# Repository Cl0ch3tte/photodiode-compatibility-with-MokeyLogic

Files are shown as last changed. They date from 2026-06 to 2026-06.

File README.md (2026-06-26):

# photodiode-compatibility-with-MokeyLogic

Open-hardware photodiode circuit that generates sub-millisecond event markers
synchronized with on-screen visual stimuli on a 144Hz display, designed to
complement eye-tracking data collected with MonkeyLogic.

# Overview
The detector converts a light signal into an electrical signal using a
photodiode and a transimpedance amplifier (TIA), then compares it to an
adjustable threshold to produce a clean logic signal. An Arduino timestamps
this signal in microseconds and streams it over USB serial; a Python script
logs it to CSV, which can then be merged with keyboard-generated event
markers for full experimental synchronization.

# Hardware

- **Photodiode:** SFH206K
- **Amplifier:** LM358 (single dual op-amp: one stage as TIA, one as
  threshold comparator with hysteresis)
- **Supply:** single 5V rail
- **Output:** BNC (analog) + digital logic line to the Arduino

Full schematic, component justification, and bill of materials are in
[`docs/Dossier_de_conception.pdf`](docs/Dossier_de_conception.pdf).

## Firmware

The Arduino reads the comparator's digital output, timestamps it with
`micros()`, and writes `timestamp,state` lines over USB serial at 115200
baud.

## Software

`acquisition_pcclock.py` logs the Arduino stream to a timestamped CSV.
`merge_file_auto.py` aligns and merges the Arduino CSV with a keyboard
marker CSV (useful when acquisition runs across two separate PCs), using a
shared SYNC marker as the time reference.

## Getting started

1. Build the circuit following the schematic
2. Flash 'test_arduino.ino' to the Arduino.
3. Run `acquisition_pcclock.py` to start logging.
4. Use `merge_file_auto.py` if combining with keyboard event markers.

Chloé Lapaquellerie — BUT GEII, IUT Lyon 1
Internship at INSERM SBRI Lyon, Dehay team (Cerebral Cortex and Connectome)

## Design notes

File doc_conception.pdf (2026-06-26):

# Conception d’un détecteur photodiode pour

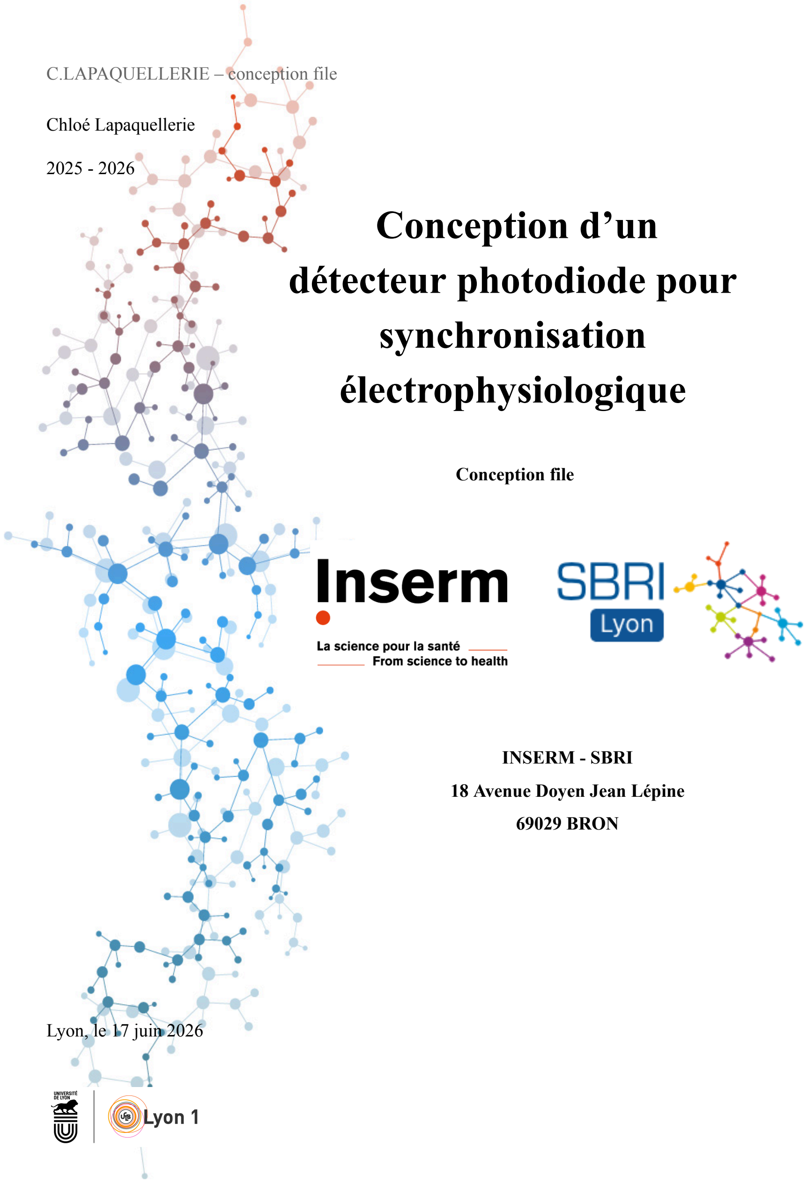
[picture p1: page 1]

C.LAPAQUELLERIE – conception file

Chloé Lapaquellerie

2025 - 2026

# synchronisation électrophysiologique

Conception file

INSERM - SBRI

### 18 Avenue Doyen Jean Lépine

69029 BRON

Lyon, le 17 juin 2026

C.LAPAQUELLERIE – Conception File | 2

## Abstract

Ce rapport présente les travaux réalisés lors d'un stage de dix semaines au sein de l'équipe Dehay-Kennedy de l'Institut Cellule Souche et Cerveau, INSERM U 1208 Lyon, dans le cadre d'une deuxième année de BUT Génie Électrique et Informatique Industrielle. La mission confiée consiste à concevoir et réaliser un circuit électronique de détection optique destiné à synchroniser des stimuli visuels avec des enregistrements électrophysiologiques, ainsi qu’une étude comportementale avec une précision temporelle inférieure à la milliseconde. Le circuit repose sur une photodiode SFH206K associée à un amplificateur opérationnel (AOP), le LM358, le circuit est alimenté en single supply 5V. Une chaîne d'acquisition complète a été développée, intégrant une carte Arduino UNO pour la récupération des données et un script Python pour l'enregistrement des données au format CSV. Le prototype a été validé en conditions réelles sur un écran LCD 144 Hz, le schéma KiCAD a été réalisé, ainsi qu’un boîtier en modélisation 3D à l’aide du logiciel de CAO Fusion 360. En vue d’avoir un projet complet et réutilisable par d’autres laboratoires, un dossier complet est en finalisation sur la plateforme GitHub.

## Table des matières

Table des Illustrations et tableaux | 9
Table des Annexes | 10
Introduction Générale | 13
I. INSERM, un institut ancré | 15
I.1 L’INSERM en quelques mots | 15
I.2 Objectifs et but | 16
I.3 Planning du stage | 16
II. INSERM Lyon | 18
II.1 INSERM Lyon - site de Bron | 18
II.2 L’équipe Dehay-Kennedy: Cerebral Cortex and Connectome | 19
III. Présentation de la mission | 21
III.1 Objectifs | 21
III.2 Analyse préliminaire | 21
III.3 Contraintes et enjeux | 22
IV. Mise en oeuvre de la mission | 23
IV.1 Analyse complète | 23
Etage 1 : amplificateur transimpédance (TIA) | 24
Etage 2 : comparateur | 27
IV.2 Test avec le premier prototype | 28
IV.3 Débogage - problèmes rencontrés et solutions | 30
Problème 1 : photodiode montée à l’envers | 31
Problème 2 : zone morte du LM358 en single supply | 31
IV.4 Réalisation du PCB avec KICAD | 32
IV.5 Réalisation du boîtier en CAO | 34
IV.6 Acquisition des données script Python et Arduino | 36
Architecture | 36
IV.7 Premiers résultats (au 16 juin 2026, veille de rendu) | 41
V. Conclusion Générale | 43
VI. Bilan technique | 44
VI.1 Résultats et évaluation | 44
VI.2 Discussion et analyse des solution retenues | 45
VII. Bilan de Compétences | 47
VII.I Concevoir la partie GEII d’un système | 47
VII.II Implanter la partie GEII d’un système | 50
VII.III Vérifier la partie GEII d’un système | 54

VII.IV Maintenir la partie GEII d’un système | 58
VIII. Bilan personnel | 59
VIII.1 Discussion | 59
VIII.2 Avenir | 59
Appendix | 61
Références | 66

## Table des Illustrations et tableaux

Figure 2 – Organigramme du SBRI (2024) | 18
Figure 3 – Schéma électronique complet KiCAD | 23
Figure 4 – Architecture interne générale du LM358AP | 24
Figure 5 – Etage 1: le TIA | 25
Figure 6 – Etage 2: le comparateur | 27
Figure 7 – Montage sur breadboard | 29
Figure 8 – Première version du circuit - non fonctionnel | 30
Figure 9 – Plan du PCB sur KiCAD | 32
Figure 10 – Visualisation 3D de la carte électronique face-avant | 33
Figure 11 – Visualisation 3D de la carte électronique face-arrière | 33
Figure 12 – Boîtier en vue gauche-haut | 34
Figure 13 – boîtier vue bas-droite | 35
Figure 14 – Flowchart du programme Arduino | 37
Figure 15 – Flowchart programme Python | 39
Figure 16 – Exemple d’un enregistrement de fichier | 40
Figure 17 – Exemple d’utilisation du fichier CSV sur excel | 41
Figure 18 – Brouillon n°1 des calculs | 48
Figure 19 – Brouillon n°2 des calculs | 49
Figure 20 – Premier prototype du circuit | 50
Figure 21 – Recherches sur le boîtier | 52
Figure 22 – Recherches sur le boîtier n°2 | 53
Figure 23 – Premiers tests avec l’oscilloscope et prise de notes PC | 54
Figure 24 – Prise de notes pendant une phase de tests | 56
Figure 25 – Prise de notes pendant la phase de tests final | 57
Tableau 1 – Contraintes et enjeux | 22
Tableau 2 – Compétences GEII | 47

## Table des Annexes

Annexe I – Organigramme équipe Dehay | 61
Annexe II – Exemple d’une image de stimuli avec le carré de pixel pour la photodiode en haut
sur la droite | 61
Annexe III – Photodiode soudée sur l’autre face | 62
Annexe IV – Script Arduino | 63
Annexe V - Script Python Partie 1 | 64
Annexe VI – Script Python Partie 2 | 65

## Introduction Générale

Dans le cadre de ma deuxième année de BUT Génie Electrique et Informatique Industrielle (GEII), parcours Electronique et Systèmes Embarqués (ESE) à l’Université Claude Bernard Lyon 1, il est requis de réaliser un stage d’un minimum de 8 semaines au sein d’une entreprise se rapportant aux compétences acquises pendant le diplôme. J’ai ainsi effectué un stage de dix semaines de avril à juin au sein du laboratoire Stem Cell and Brain Research Institute (SBRI) unité Institut National de la Santé et de la Recherche Médicale (INSERM), en co-tutelle avec l’Université Claude Bernard Lyon 1.

Le projet est une extension à l’utilisation de MonkeyLogic. Les solutions actuelles répondent pour la plupart à des besoins spécifiques présentant donc des limitations. La nécessité d’avoir un système modulable et peu onéreux à pour objectif de proposer une solution adaptée et spécifique Le projet consiste à concevoir un système de mesure optique basé sur une photodiode. Le signal lumineux est converti en courant, puis transformé en tension via un amplificateur transimpédance (TIA) réalisé avec un LM358. Cette tension ainsi acquise, est transmise par un connecteur BNC, permettant le traitement du signal analogique selon le besoin.

Une seconde partie du circuit permet la détection d’un seuil lumineux grâce à un comparateur intégré dans le même amplificateur opérationnel. Les données sont ensuite transmises à une carte Arduino afin d’être enregistrées sous forme de fichier CSV.

Ce système permet donc à la fois une mesure analogique continue et une détection logique binaire.

## III. Présentation de la mission

III.1 Objectifs

L’objectif est de concevoir, mettre en place et utiliser un système électronique permettant de détecter l’apparition d’un stimulus lumineux sur un écran 144Hz. Depuis un cahier des charges, la mission permettait avec flexibilité, de concevoir le dispositif selon les besoins, insistant sur une précision temporelle à la milliseconde minimum dû à la fréquence d'échantillonnage du système de mesure des mouvements oculaires qui est de 1000 Hz, soit une mesure toutes les milliseconde. Ce système permet donc de générer deux signaux afin de satisfaire les besoins de l’équipe concernée :

- Un signal analogique proportionnel à l’intensité lumineuse, destiné à une carte d’acquisition NI BNC2090A via LabView notamment. Des paramétrages doivent être ajoutés sur cette sortie dans l’application, le montage étant un montage inverseur.
- Un signal numérique (HIGH/LOW) pour la détection d’événements et l'enregistrement des timestamps via Arduino. Utilisable directement grâce à un fichier python convertissant les données brutes en un fichier CSV.

III.2 Analyse préliminaire

Une première analyse a permis d’identifier les principales contraintes techniques du projet. D’abord, l’écran 144Hz, affichant 144 images par seconde soit une image toutes les 6.94ms. La détection doit donc être sur cette échelle de temps.

Le dispositif doit avoir une capacité de captation inférieure à 1ms, le stimuli étant envoyé toute les 1 ms, toutefois, le taux de rafraîchissement de l’écran nous permettrait une plus grande flexibilité.

Des composants initiaux étaient fournis, une photodiode, un potentiomètre, un AOP LM358, ces composants devaient apparaître dans le projet, autrement l’ajout d’autres composants était laissé libre. La solution retenue repose donc sur une architecture en deux étages : un amplificateur transimpédance (TIA) pour convertir le courant de la photodiode en tension, suivi d’un comparateur à Trigger Schmitt pour générer un signal logique propre.

III.3 Contraintes et enjeux

Plusieurs contraintes techniques ont orienté la conception du circuit:

Contraintes | Valeur | Justification
Résolution temporelle | <1ms | 144Hz = 6.94ms, apparition stimuli
durée de session | ~4h | Protocol expérimental
Alimentation | 5V/3A single supply | Suffisant, peu coûteux
Sorties | analogique + numérique | BNC2090A et Arduino
compatibilité | VSCode, Arduino, Python, C++, LabVIEW, Matlab? | outils disponibles au labo
stabilité thermique | dérive <1% sur 4h | SFH206K : +0.18%/K
Tableau 1 – Contraintes et enjeux | source: production personnelle

## I. Coût

X.1 Estimation du coût

Les produits présentés sont ceux qui ont été utilisés, tant que la référence est identique, le choix

du fabricant est quant à lui moins important.

Composant | Fabricant | quantité minimale
Coût | lien web (Mai
2026)

LM358 | Texas Instrument
(de préférence)
1 | 8.25€/5 unité | https://fr.rs-onlin e.com/web/p/am plificateurs-oper ationnels/197726
| | 5 (https://fr.rs-online.com/web/p/amplificateurs-operationnels/1977265) ou https://www.digi key.fr/fr/product s/detail/texas-ins truments/LM358 P/277042?gclsrc =aw.ds&gad_sou rce=1&gad_cam paignid=152153 454&gbraid=0A AAAADrbLlgq B2UV5AgsTN3 3TqG40FY_N& gclid=CjwKCAj wt7XQBhBkEiw AtStpp02cAwa8 KRMOzUmNhR BCu0NmLNIoIn 92SHsSUgylwN g7m5T8sxhbvho C04kQAvD_Bw E (https://www.digikey.fr/fr/products/detail/texas-instruments/LM358P/277042?gclsrc=aw.ds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)
SFH206K | AMS OSRAM | 1 | 6.05€ (5 unités) | https://fr.rs-online.com/web/p/photodiodes/654865 9 (https://fr.rs-online.com/web/p/photodiodes/6548659)
Résistance 1MΩ | TE Connectivity | 2 | 1.55€/10 unités | https://fr.rs-online.com/web/p/resi stances-traversan tes/2141535 (https://fr.rs-online.com/web/p/resistances-traversantes/2141535)
Résistance 10kΩ | Arcol | 4 | 3.50€/5 unité | https://fr.rs-online.com/web/p/resi stances-traversan (https://fr.rs-online.com/web/p/resistances-traversantes/4877141)

| | | | tes/4877141 (https://fr.rs-online.com/web/p/resistances-traversantes/4877141)
Capacité 100pF | TDK | 1 | 1.70€/10 unités | https://fr.rs-online.com/web/p/con densateurs-cera mique-monocou che/2621945 (https://fr.rs-online.com/web/p/condensateurs-ceramique-monocouche/2621945)
Coût total depuis les références (sans frais de port) = 65.79€ PT-10 | Amphenol Piher Sensing Systems | 1 | 0.48$/unité | https://www.digikey.fr/fr/products/detail/ampheno l-piher-sensing-s ystems/PT10MH 01-103A2020-I-PM-S/9555907 (https://www.digikey.fr/fr/products/detail/amphenol-piher-sensing-systems/PT10MH01-103A2020-I-PM-S/9555907)
Bloc de jonction CI série MKDSN 2.5/2-5.08 2 contacts Phoenix Contact | Phoenix contact | 2 | 1.07€/unité | https://fr.rs-online.com/web/p/bor niers-enfichables /8045095 (https://fr.rs-online.com/web/p/borniers-enfichables/8045095)
RS PRO BNC Connecteur BNC Femelle Montage sur circuit imprimé 50 Ω Soudure Droit | RS PRO | 1 | 2.79€/unité | https://fr.rs-online.com/web/p/con necteurs-coaxiau x/5260279 (https://fr.rs-online.com/web/p/connecteurs-coaxiaux/5260279)
Bloc d’alimentation 5V | RS PRO | 1 | 7.47€/unité | https://fr.rs-online.com/web/p/adaptateurs-ac-dc/1753297?searchId=04d6a79d-95de -4a1f-9e7f-f3b0f f57944d (https://fr.rs-online.com/web/p/adaptateurs-ac-dc/1753297?searchId=04d6a79d-95de-4a1f-9e7f-f3b0ff57944d)

## IV. Mise en oeuvre de la mission

IV.1 Analyse complète

L’analyse complète du besoin et des composants nous a amené sur un circuit organisé en deux étages, exploitant les deux amplificateurs du LM358. La photodiode étant fondamentalement une source de courant, il est nécessaire de transformer cette dernière en tension afin d’être une source exploitable. En effet, la photodiode capte la quantité de lumière reçue et génère un courant proportionnel à cette quantité de l’ordre de quelques microampères, ce courant est trop faible en tant que tel et dans le mauvais format, ne permettant pas son utilisation. Un système d’acquisition s’attend à une tension, pas un courant pour fonctionner. Ainsi, un premier étage est câblé en Amplificateur transimpédance (TIA) qui permet de convertir le courant de la photodiode en tension avec un gain Rf = 1MΩ. Le second étage est lui un comparateur à seuil fixe. Il compare la sortie du TIA à une tension seuil déterminée avec le potentiomètre et donne donc un signal logique de déclenchement. Le schéma électronique suivant présente la configuration finale du projet:

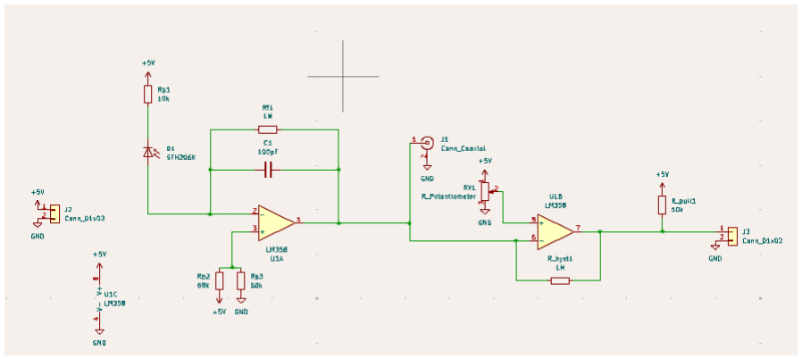
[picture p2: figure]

Figure 3 – Schéma électronique complet KiCAD | source – production personnelle

Le choix du LM358 tant bien qu’imposé nous a laissé une certaine flexibilité. Compatible avec une alimentation simple 5V (single supply), le circuit a été architecturé autour de cette contrainte. Nous pouvons constater dans la figure suivante représentant l’architecture générale du LM358, qu’il possède bien deux étages, les deux étant utilisés dans notre montage.

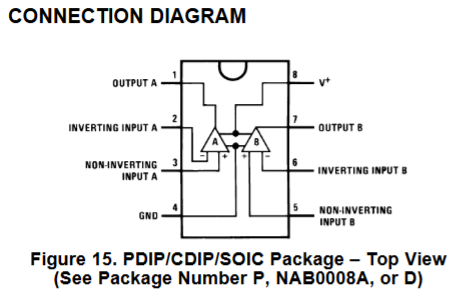
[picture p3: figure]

Figure 4 – Architecture interne générale du LM358AP | source – datasheet LM358 Texas
Instrument

Toutefois, la compréhension du single supply et de l'interaction avec l’AOP n’était pas tout à fait maîtrisée, nous amenant à une reconstruction partielle du circuit après une phase de test et un début de mise en place. Des étapes qui seront décrites ultérieurement dans ce rapport.

Etage 1 : amplificateur transimpédance (TIA)
Le rôle du TIA est de convertir le courant généré par la photodiode en une tension. Pour se faire, on s’appuie sur un principe de base d’un AOP idéal en boucle fermée: les deux entrées sont maintenues à la même tension par une boucle de contre-réaction. Ce comportement est dû au fonctionnement de l’AOP en régime linéaire qui cherche à minimiser la différence de potentiel entre ses entrées conformément à l’équation ε = V+ - V- ~ 0.

Le pont diviseur maintient la tension non inverseuse (pin 3) à une valeur Vref. Simultanément, la boucle de contre-réaction force la pin 2 à rester à une valeur proche de Vref. Cette entrée se comporte donc comme un nœud de référence virtuel, qui peut être appelé masse virtuelle puisque Vref joue le rôle de référence sur le montage ici.

On peut voir sur la figure suivante le TIA avec une première partie du LM358, la boucle de rétroaction, le pont diviseur en pin 3 ainsi que la photodiode.

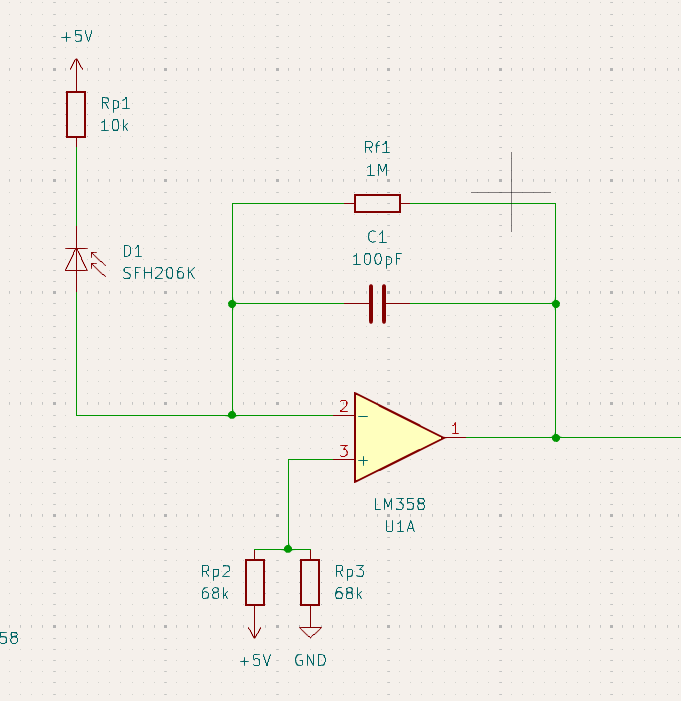
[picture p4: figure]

Figure 5 – Etage 1: le TIA | source – production personnelle

La photodiode SFH206K est polarisée en mode photoconducteur. Sa cathode est reliée au rail 5V via une résistance de 10kΩ, son anode est connectée à l’entrée inverseuse du premier AOP (pin2) du LM358. La résistance Rf = 1MΩ placée en parallèle avec le condensateur Cf = 100pF est connectée entre la sortie (pin1) et l’entrée inverseuse (pin2). L’entrée non-inverseuse (pin3) est connectée au nœud d’un pont diviseur composé de deux résistances 68kΩ en série entre le rail 5V et le GND, fournissant ainsi une tension première tension de référence Vref1 ~2.5V. Ce choix est imposé par une limitation physique du LM358 en alimentation single supply. En effet, sa plage d’entrée en mode commun ne s’étend pas jusqu’à 0V ni 5V, elle est légèrement au-dessus du 0V, et en dessous du 5V. Avec le pin3 directement à 0V, l’AOP entre dans une zone morte où il ne peut plus amplifier correctement et sature sa sortie vers le bas quelle que soit la différence d’entrée. En relevant le pin 3 à ~2.5V soit la moitié de la plage de la tension d’entrée, on a donc une plage virtuelle pour l’AOP de -2.5V à +2.5V, permettant l’utilisation réelle de l’AOP, sans dépasser le comportement normal et usuel du composant. Nous rentrerons dans de plus amples détails sur ce fonctionnement ultérieurement.

La fonction de transfert du TIA simplifiée est: Vout = Vref - Iph x Rf

En basse fréquence, Zf ~ Rf = 1MΩ. La fréquence de coupure du filtre RC est donc fc = 1/(2.π.Rf.Cf) ~1.6kHz largement suffisant pour détecter les transitions liées à l’apparition du stimulus sur l’écran 144Hz.

Du fait de la configuration inverseuse du TIA, la tension en sortie (pin 1) diminue lorsque la luminosité augmente par rapport à Vref. Ainsi, à l’obscurité pin1 est proche de 2.5V, tandis qu'en présence du stimulus blanc (de 60x60 pixels) à l'écran, pin 1 descend de manière significative en dessous de 2.5V. Ce comportement est corrigé au niveau du comparateur par le réglage du seuil avec le potentiomètre. Pour la sortie analogique, la correction se fera dans le logiciel associé à la carte d’acquisition.

Enfin, le condensateur Cf est essentiel à la stabilité du montage afin de limiter les oscillations parasites dûes au gain élevé de 1MΩ et les effets liés à la capacité de jonction de la photodiode.

Etage 2 : comparateur

Le second AOP du LM358 est câblé en comparateur. Son entrée inverseuse (pin 6) est reliée à la sortie du TIA (pin 1). Son entrée non-inversée (pin 5) reçoit la tension de seuil fournie par le potentiomètre câblé entre le +5V et le GND. Cette tension seuil est déterminée à la mesure en tension au pin 1. On récupère la valeur avec lumière et à l’obscurité, on place le curseur du potentiomètre sur la valeur milieu de la plage trouvée. On retrouve dans la figure ci-après la configuration du deuxième étage avec la deuxième partie du LM358, la résistance d'hystérésis et celle de pull-up ainsi que le potentiomètre.

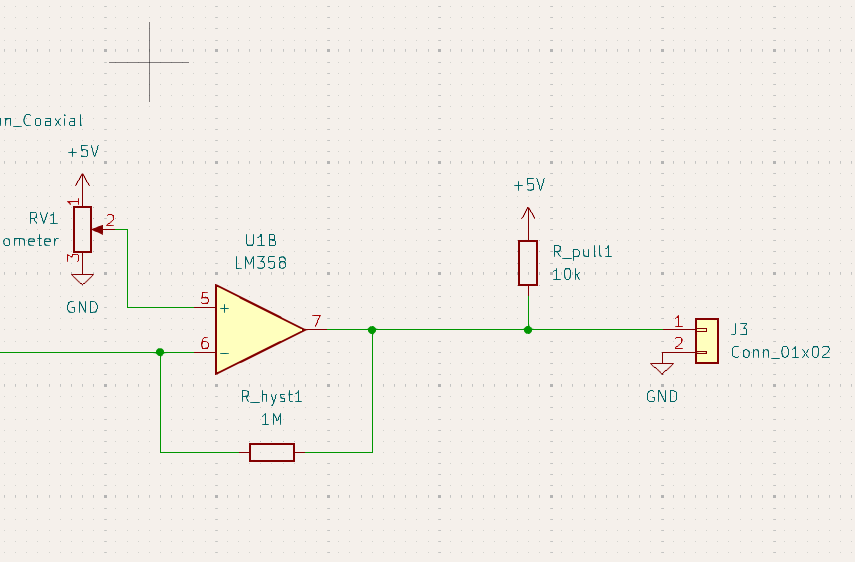
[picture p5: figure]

Figure 6 – Etage 2: le comparateur | source – production personnelle

Une résistance de pull-up est placée entre le +5V et la sortie (pin 7), celle-ci est indispensable. De fait, son intérêt vient directement de l’architecture interne du composant. Le LM358 présente une sortie à collecteur ouvert NPN, il fonctionne comme un interrupteur commandé, c’est-à-dire quand le comparateur décide que la sortie doit être LOW, le transistor entre en conduction et relie la pin de sortie au GND, il absorbe donc le courant. En revanche, quand le comparateur décide que la sortie doit être HIGH, le transistor se bloque, laissant la sortie flottante, sans la relier à l’alimentation. Sans résistance de pull-up, la sortie en état HIGH serait donc reliée à rien et la tension mesurée est autour de 0.66V, soit la mesure de la tension “résiduelle” du composant, donc ni un état logique HIGH, ni un LOW.

Enfin, une résistance d’hystérésis Rhyst = 1MΩ est connectée entre la sortie (pin 7) et l’entrée non-inverseuse (pin 5). Elle introduit une légère rétroaction positive qui élargit la zone de basculement du comparateur, évitant les oscillations parasites lorsque le signal d’entrée est proche du seuil. La logique du système est donc la suivante:
- Pas de stimulus à l’écran - Fond noir : pin 1 ~2.5V → pin 6 > pin 5 → pin 7 = LOW (~0V)
- Stimulus blanc à l’écran : pin 1 descend sous le seuil → pin 6 < pin 5 → pin 7 = HIGH (~4.6V)
Le seuil est réglé avec le potentiomètre pour se situer entre la valeur de pin 1 en fond noir et la valeur pin 1 avec la tâche blanche. Ce réglage est effectué une fois en conditions réelles d’utilisation et dépend de la luminosité de l’écran et des conditions d’éclairages ambiant.

IV.2 Test avec le premier prototype

Un prototype sur platine d’essai a été réalisé avant le PCB afin de valider le principe de fonctionnement. Ces tests étaient d’abord effectués en utilisant le flash d’un téléphone, rendant les mesures plus simples que sur un écran. Comme le montre la configuration dans la figure ci-contre:

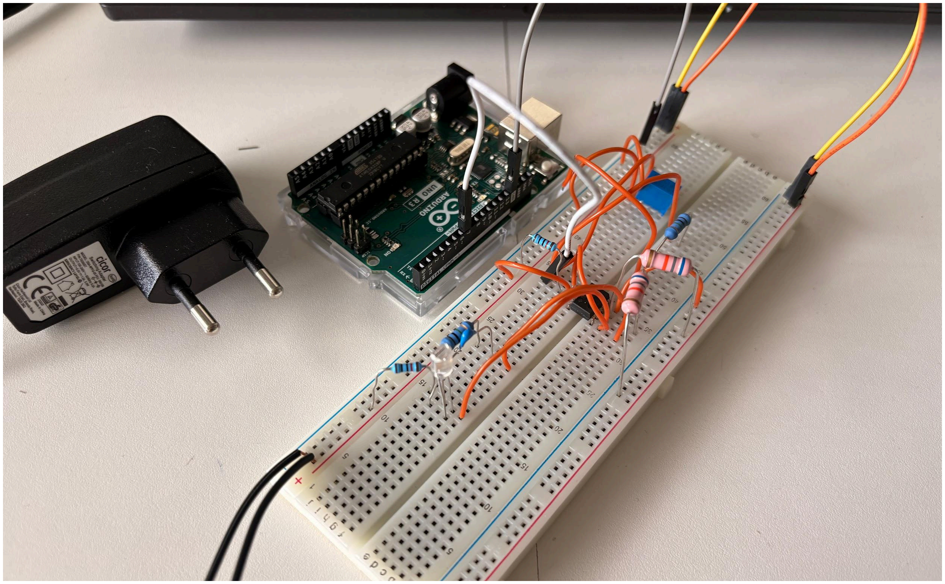
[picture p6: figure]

Figure 7 – Montage sur breadboard | sources – photo personnelle

Les premiers tests ont permis de montrer des comportements anormaux tels que la sortie TIA saturée, ou les tensions incohérentes sur les entrées et sorties des deux étages. Les tests ont été conduits bloc par bloc afin de détecter un potentiel problème à la source et construire pas à pas plutôt que de revenir en arrière et potentiellement ne pas tomber sur le véritable problème. Une fois les problèmes résolus, les mesures ont pu confirmer le comportement attendu: en fond noir la pin 1 se stabilisait autour de 2.2V, lorsqu’un stimuli était présenté, cette dernière descendait rapidement sous le seuil provoquant donc un basculement sur la pin 7. Le signal de déclenchement a ensuite été vérifié avec le script python, mettant en évidence le bon fonctionnement du prototype.

IV.3 Débogage - problèmes rencontrés et solutions

Plusieurs ajustements ont été nécessaires au cours du prototypage:
- Augmentation de Rf de 68kΩ à 1MΩ : le gain initial était insuffisant pour détecter la lumière d’un écran (signal <0.1V avec 68kΩ, 1.6V avec 1MΩ)
- Correction de l’orientation de la photodiode SFH206K, la fenêtre sensible étant sur le côté, ajouter une légère orientation permet d’obtenir un meilleur résultat.
- photodiode soudée sur l’autre face pour optimiser l’espace (voir annexe III)
Après ces corrections mineures, une phase intense de débogage a dû avoir lieu. Cette dernière s’est étalée sur plusieurs jours, ce qui était également la partie la plus formatrice du stage. En effet, les résultats incohérents du premier prototypage et le fait que ces derniers soient instables d’une session à l’autre m’ont amené à vérifier le circuit point par point pour chercher l’origine de ces résultats.

Le circuit à cet instant était le suivant :

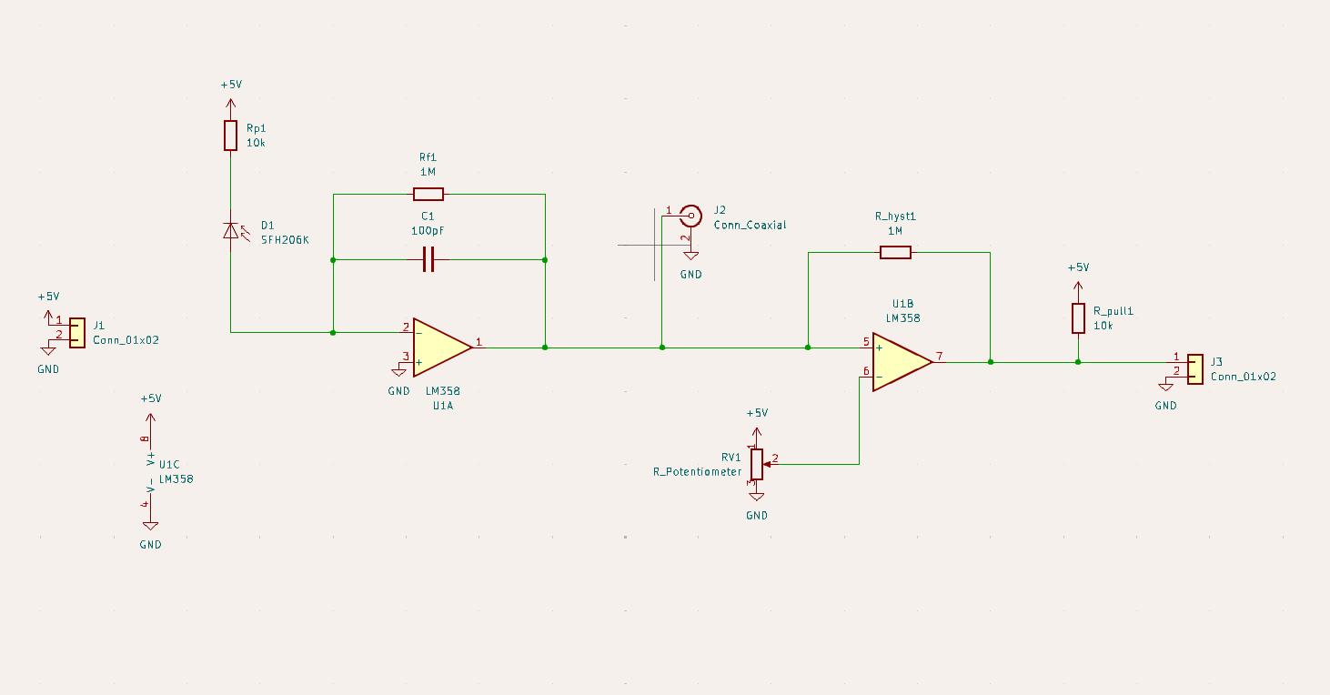
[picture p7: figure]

Figure 8 – Première version du circuit - non fonctionnel | source – prod. personnelle

Sur l’instant, le problème ne me semblait pas évident, n’ayant pas pris le recul nécessaire sur mon circuit et n’étant pas suffisamment à l’aise avec certaines notions d’électronique. Toutefois, je souhaitais chercher par moi-même avant de faire appel à une aide extérieure.

Problème 1 : photodiode montée à l’envers

La photodiode SFH206K a d’abord été montée en polarité inverse lors des tests platines, l’anode étant généralement la patte la plus longue, j’ai ainsi placé la photodiode avec ce réflexe. Toutefois, en vérifiant plusieurs fois le circuit, je l’ai inversée par mégarde à plusieurs reprises, la photodiode conduisait donc en mode direct, court-circuitant le noeud de la pin 2 vers une tension fixe, la valeur de la résistance ne dépendait donc plus de l’intensité lumineuse.

Problème 2 : zone morte du LM358 en single supply

Avec la pin 3 directement reliée au GND, le TIA présentait systématiquement une sortie pin 1 saturée à 0V, quelle que soit la tension appliquée sur pin 2. Ce comportement est en réalité dû à une limitation physique du composant. L’alimentation en single supply ne permet pas à la plage d’entrée de descendre jusqu’au GND et en deçà. Ainsi, en dessous d’environ 0.4V sur les entrées, l’AOP sort de sa zone de fonctionnement linéaire. Il ne peut plus maintenir de virtual ground ni appliquer sa fonction transfert et sature donc sa sortie vers le bas. Ce comportement était donc anormal et instable, tous les résultats de mesure devenaient donc incohérents car on cherchait à interpréter des tensions dans un modèle qui n’était plus valide. Un résultat non souhaité et le plus long à détecter. C’est avec l’aide de M. Robin et M. Bouron que ce problème a pu être solutionné. L’ajout d’un pont diviseur de 2 résistance 68kΩ sur la pin 3 a permis de laisser l’AOP dans sa zone fonctionnelle fournissant une tension de référence Vref = 2.5V, “déplaçant” virtuellement la plage de 0V-5V à (-2.5V)-2.5V.

IV.4 Réalisation du PCB avec KICAD

A l’issue de la validation du prototype sur breadboard, la conception du schéma électronique sur KiCAD a été réalisée. Le schéma reprend l’architecture validée avec les ajouts précédemment mentionnés. La première différence entre le prototype sur breadboard et la carte électronique réside dans l’ajout du connecteur BNC. Ce schéma à permis la fabrication du PCB qui nous a été livré puis implanté au boîtier réalisé par la suite en modélisation 3D avec un logiciel de CAO. La carte finale fait 105 mm par 65 mm, les pistes ont été optimisées de manière convenable avec une épaisseur de 0.3mm. Des teardrops ont également été ajoutées pour favoriser un meilleur soudage, un plan de masse a également été ajouté au design final comme en témoignent les deux figures ci-contre:

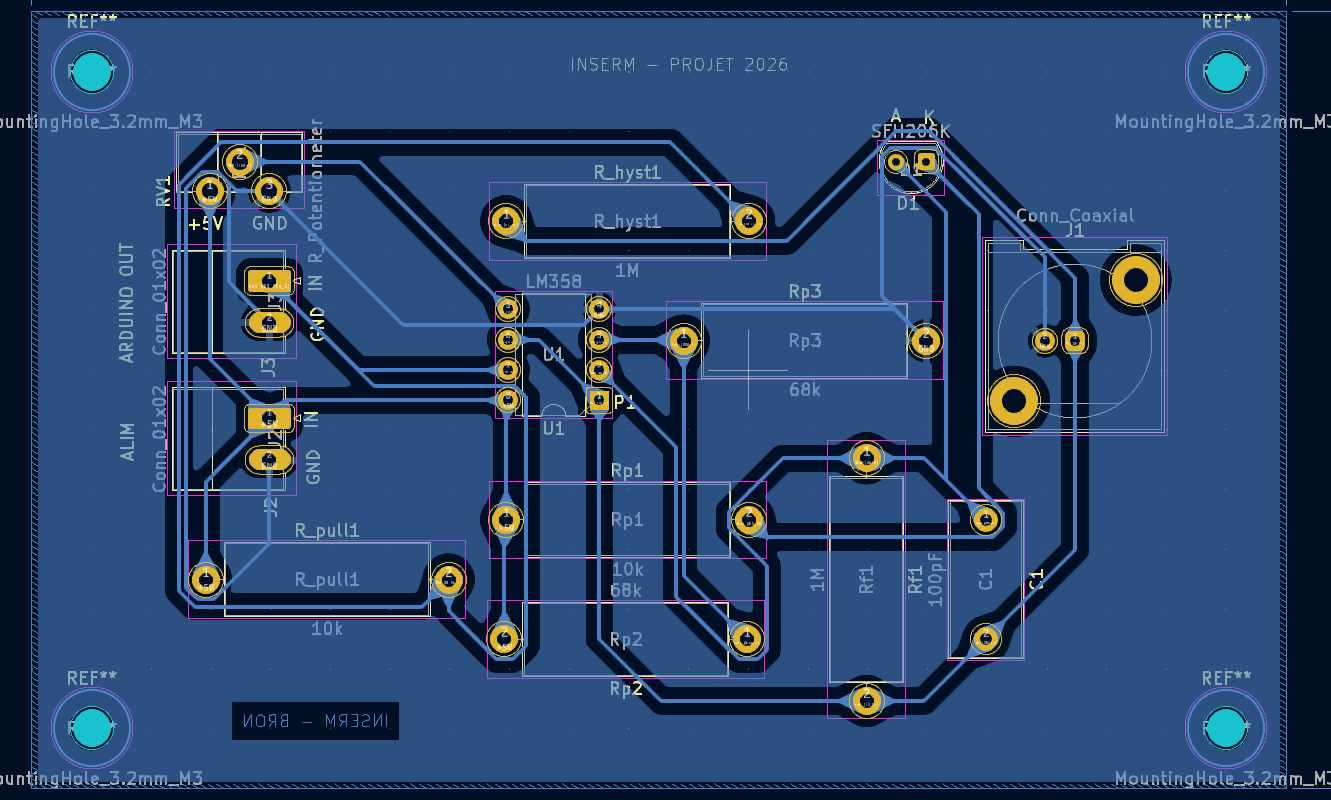
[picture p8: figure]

Figure 9 – Plan du PCB sur KiCAD | source – production personnelle

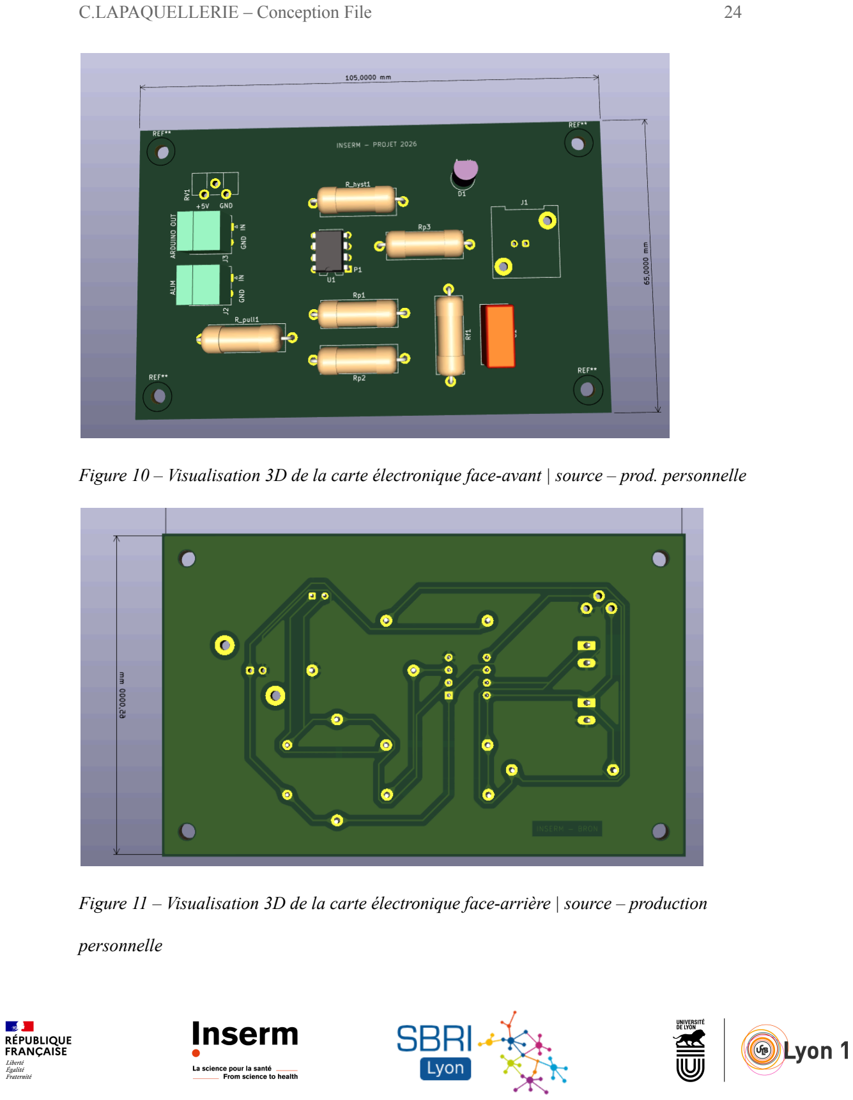
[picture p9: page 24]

Figure 10 – Visualisation 3D de la carte électronique face-avant | source – prod. personnelle
Figure 11 – Visualisation 3D de la carte électronique face-arrière | source – production

personnelle

IV.5 Réalisation du boîtier en CAO

Afin de rendre le dispositif utilisable facilement, un boîtier de maintien a été conçu sous Fusion 360 et imprimé en 3D à l’aide d’une imprimante Prusa pilotée par le logiciel PrusaSlicer. Le boîtier intègre un système d’accroche pour le PCB afin de le maintenir à l’horizontal tout en laissant passer les fils de connexions nécessaires par des trous d’un diamètre de 3mm. Comme le montre la photo ci-contre:

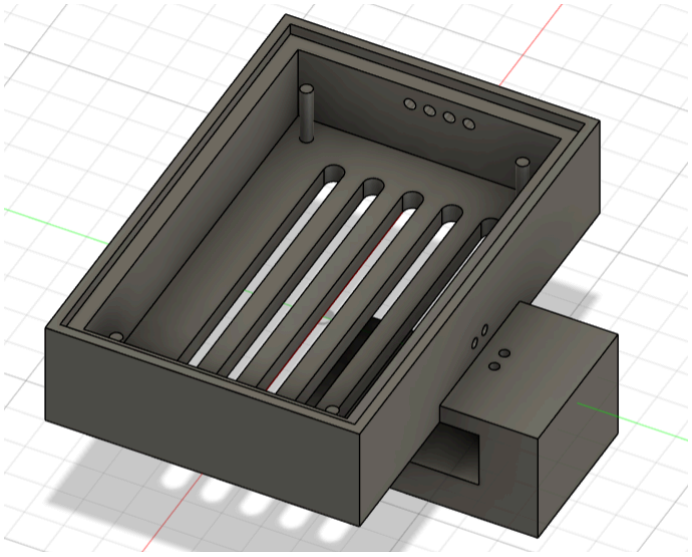
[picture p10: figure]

Figure 12 – Boîtier en vue gauche-haut | source – production personnelle

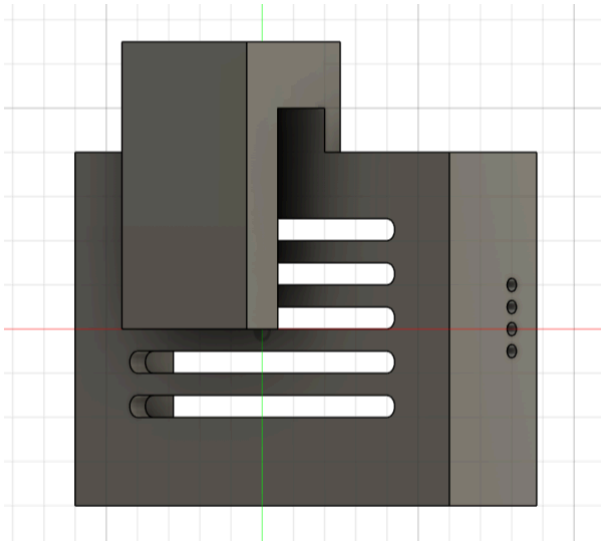
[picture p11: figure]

Figure 13 – boîtier vue bas-droite | source – production personnelle

D’autre part, il intègre un système d'accroche à double utilité, d’abord pour maintenir le boîtier sur l’écran, ensuite une encoche a été faite dans ce “bras” pour pouvoir placer la photodiode au plus proche de l’écran et en évitant les parasites lumineux tels que l’éclairage de la pièce expérimentale. La résistivité des fils reliant la photodiode à la carte électronique reste négligeable dû au gain. De plus, l’adaptabilité du circuit avec le potentiomètre réglable permet de garder une sérénité quant à ce choix de conception simplifié.

IV.6 Acquisition des données script Python et Arduino

Afin de valider le fonctionnement du circuit et d'enregistrer les données de déclenchement pour une analyse ultérieure, une chaîne d'acquisition logicielle a été développée autour d'une carte Arduino uno et d'un script Python.

Architecture

La sortie trigger du circuit (pin 7) est connectée à la pin digitale 7 de l’Arduino. L’arduino lit en continu l’état logique de cette entrée et transmet les données via une connexion USB à un ordinateur, où un script Python reçoit les données, les date et les enregistre dans un fichier CSV.

Cette architecture est simple d’utilisation, quasiment complètement optimisée. Par ailleurs, l’Arduino possède une fonction “micros()” qui retourne le temps écoulé depuis le démarrage en microseconde. Afin de garantir un débit suffisant pour transmettre les états sans pertes, la communication série a été établie à 115200 bauds.

Le programme Arduino est volontairement court pour maximiser la réactivité (voir annexe IV pour le code complet). La flowchart suivante témoigne de la boucle suivie par le code:

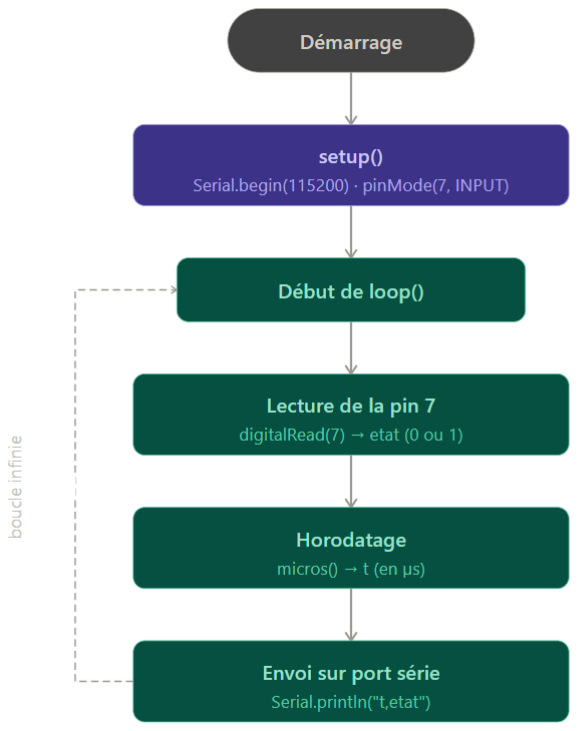
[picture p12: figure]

Figure 14 – Flowchart du programme Arduino | source – production personnelle (rendu

amélioré par IA Canva)

A chaque itération de la boucle principale, l’état logique de la pin 7 est lu via digitalRead(), puis horodaté avec micros(). Les deux valeurs sont transmises par la liaison série et enregistrées sous la forme “timestamp,etat”. Un format facilement exploitable pour un fichier CSV. Le timestamp est exprimé en microseconde, bien en dessous de la précision en milliseconde minimale demandée, cette précision permet au dispositif d’être adaptable à d’autres expériences et d’autres précisions. Il n’y a pas de delay() ajouté au code afin de permettre une exécution la plus rapide possible. Cela implique aussi que beaucoup de lignes vont être transmises et notamment beaucoup sans changement d’état, cela permettra une reconstruction plus précise de la forme du signal trigger.

Le script Python gère la réception des données séries et leur enregistrement dans un fichier CSV automatiquement horodaté. La flowchart suivante présente la structure du code:

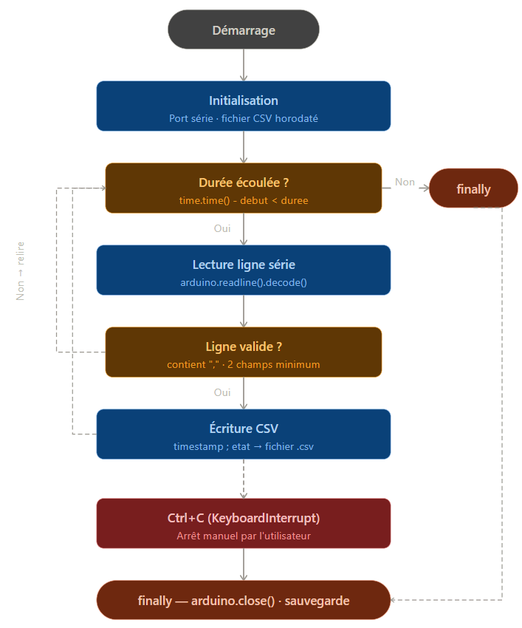
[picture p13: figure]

Figure 15 – Flowchart programme Python | source – production personnelle (rendu amélioré

par IA Canva)

Lorsque l’on lance le script (qui est consultable en annexe, voir annexe V et VI), ce dernier
génère | automatiquement | un | nom | de | fichier | horodaté | au | format
“get_JJ-MM-AAAA_HH-MM-SS.csv” évitant un écrasement de données d’une session à l’autre. Un exemple de résultat est visible sur la figure suivante:

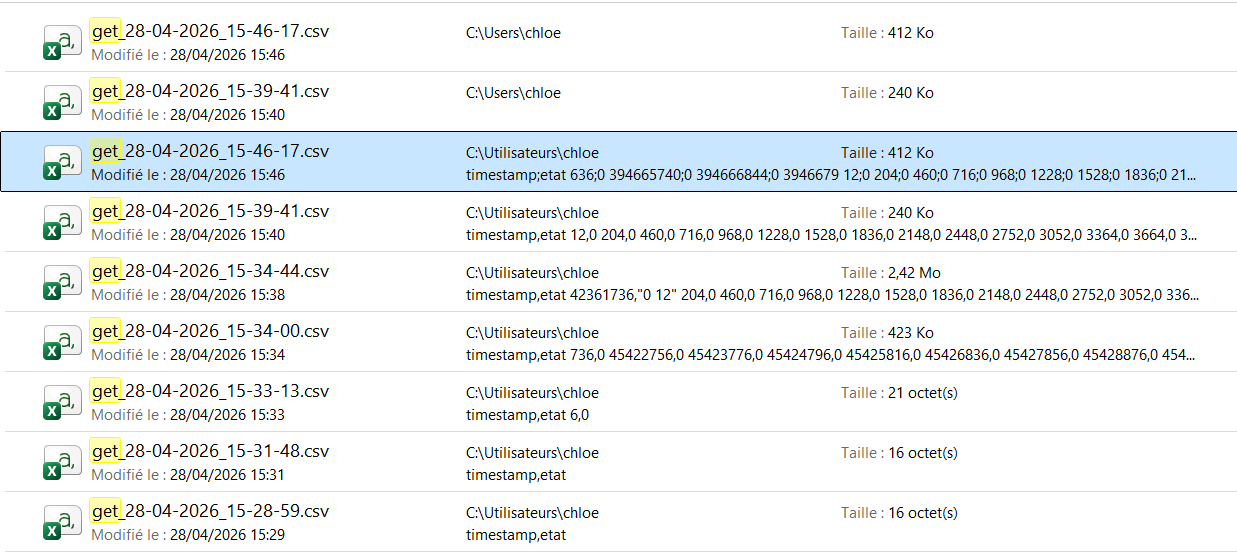
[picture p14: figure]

Figure 16 – Exemple d’un enregistrement de fichier | source – production personnelle

Un léger délai de deux secondes après l’ouverture du port série permet à l’Arduino de terminer son initialisation avant de démarrer l'acquisition. Sans ce délai les premières trames pourraient être compromises. La boucle principale tourne pendant une durée modifiable qui est actuellement de 7200 secondes soit 2h. Chaque ligne reçue est vérifiée et doit comporter la présence d’une virgule et d’au moins deux champs afin d’être contrôlée et d’éviter les trames incomplètes. Outre la durée d'acquisition, un arrêt manuel peut être fait en cas de nécessité en pressant la commande Ctrl+C déclenchant la partie KeyboardInterrupt qui ferme proprement le port série et confirme l’enregistrement du fichier. Le fichier CSV produit contient deux colonnes séparées par le point virgule, le timing et l’état qui lui correspond. Ce fichier est ensuite exploitable sur un tableur, via Matlab ou Excel par exemple, un aperçu d’un rendu Excel avec un graphique rapide est présenté comme suivant:

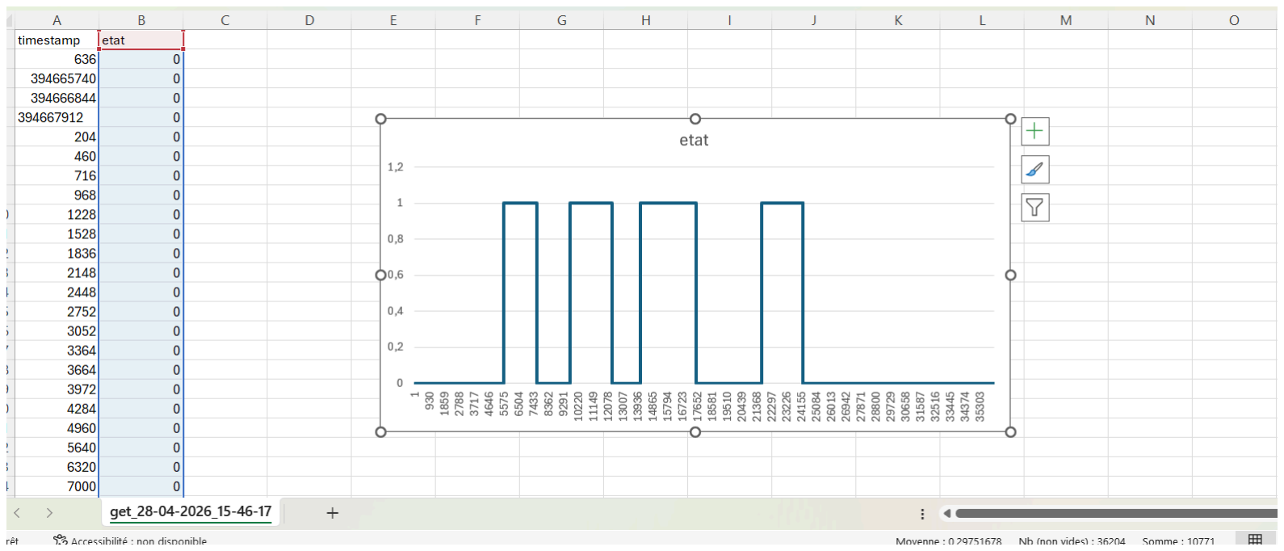
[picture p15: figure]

Figure 17 – Exemple d’utilisation du fichier CSV sur excel | source – production personnelle

On peut facilement distinguer les deux colonnes ‘timestamp’ et ‘etat’ dans les deux colonnes, l’échelle de temps est par ailleurs en microseconde, avec une capture toutes les 300µs environ. Un axe d’amélioration pourrait regarder l’échelle de temps, garder une analyse similaire mais rendre les données plus lisible sur un graphique en changeant l’échelle.

De plus, pour les essais sur sujets humains, une extension de la mission a été nécessaire. En effet, l’humain étant en capacité d’interpréter et d’exprimer ce qu’il voit, nous avions comme solution d’ajouter une interaction clavier avec trois touches, chacune correspondant à un visuel spécifique, précisé au sujet avant expérience. J’ai pu participer sur la partie code de ce nouveau facteur, et également sur son lien entre la réception photodiode et la perception de l’humain. Une contrainte principale était dans le fait que chaque script tournait sur deux ordinateurs différents, les horloges internes sur lesquelles relaient les scripts sont donc différentes. Il a fallu faire un choix de praticité, l’évidence était de conserver le signal issu de la photodiode comme le plus fidèle et le principal, son acquisition étant toutes les 300µs environ. En revanche, le script récupérant les touches clavier et le moment auquel elles ont été pressées dépendent principalement du temps de réaction d’un humain, qui est de l’ordre de 200 à 400 ms, soit 100 fois plus important que l’ordre de grandeur de la photodiode, la perte d'information serait énorme si ce script était utilisé comme script de référence. Le choix a donc été de superposer le script des touches sur le script de la photodiode, comblant les manquements par une recopie de la dernière touche enregistrée.

Une fusion des deux scripts CSV est créé par un nouveau script Python (merge_file_auto.py)
qui | permet | l’accès | aux | fichiers | enregistrés | sous | les | formats | spécifiques
“get_YYYY-MM-DD_HH-MM-SS” et “keyPressed_YYYY-MM-DD_HH-MM-SS” et procède ensuite à leur fusion par la colonne commune “timestamp_pc” tout en cherchant à faire corréler un point de remarque dénommé “SYNC” avec la valeur proche au centième de microseconde près, une fois ce point trouvé, on efface les valeurs précédentes, on ajoute les lignes nécessaire pour avoir une cadence similaire puis on fusionne les fichiers en un seul fichier CSV. Les premiers retours semblent convaincants, en revanche nous n’avons pas encore pu tester les corrélation avec les enregistrements électrophysiologiques.

## Appendix

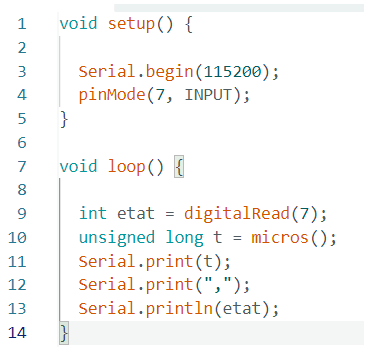
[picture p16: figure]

Annexe IV – Script Arduino | sources – production personnelle

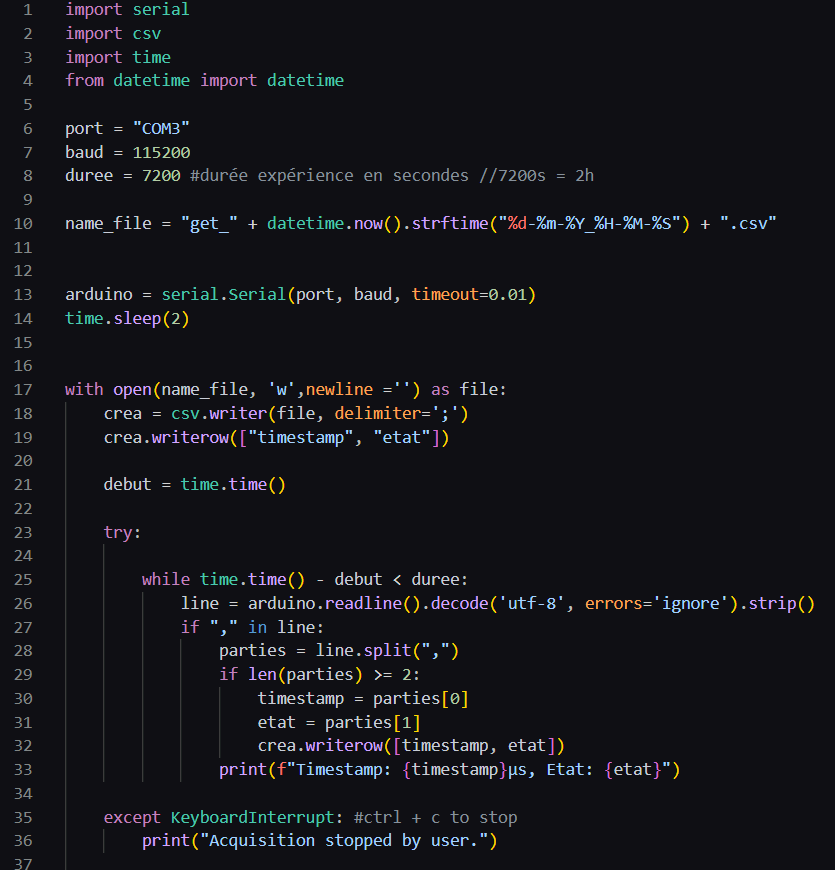
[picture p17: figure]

Annexe V - Script Python Partie 1 | sources – production personnelle

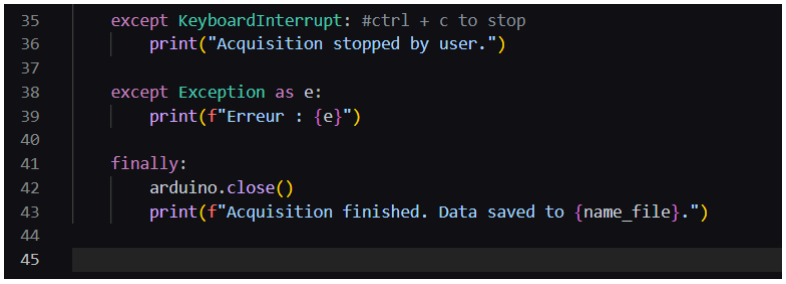
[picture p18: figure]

Annexe VI – Script Python Partie 2 | sources – production personnelle

## Références

Institut national de la santé et de la recherche médicale (INSERM). Site officiel de l’INSERM.

https://www.inserm.fr/

Wikipédia. Institut national de la santé et de la recherche médicale.

https://fr.wikipedia.org/wiki/Institut_national_de_la_sant%C3%A9_et_de_la_recherche_m%C3

%A9dicale (https://fr.wikipedia.org/wiki/Institut_national_de_la_sant%C3%A9_et_de_la_recherche_m%C3%A9dicale)

Wikipédia. Didier Samuel. https://fr.wikipedia.org/wiki/Didier_Samuel

Fonction publique. (2025). Institut national de la santé et de la recherche médicale (INSERM) –

Salon Choisir le service public.

https://www.fonction-publique.gouv.fr/salon-choisir-le-service-public-2025/les-exposants-et-leur

s-offres-demploi/institut-national-de-la-sante-et-de-la-recherche-medicale-inserm (https://www.fonction-publique.gouv.fr/salon-choisir-le-service-public-2025/les-exposants-et-leurs-offres-demploi/institut-national-de-la-sante-et-de-la-recher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)

Ville de Lyon. INSERM – Institut national de la santé et de la recherche médicale.

https://www.lyon.fr/lieu/centres-de-recherche/inserm-institut-national-de-la-sante-et-de-la-recher

che-medicale (https://www.lyon.fr/lieu/centres-de-recherche/inserm-institut-national-de-la-sante-et-de-la-recherche-medicale)

SBRI (Stem Cell and Brain Research Institute). Site officiel du SBRI. https://sbri.fr/

SBRI. Cerebral Cortex and Connectome team.

https://sbri.fr/teams/cerebral-cortex-and-connectome/

SBRI. Connectomics platform. https://sbri.fr/platforms/connectomics/

ams OSRAM. SFH 206 K Silicon PIN Photodiode – Datasheet.

https://www.alldatasheet.com/datasheet-pdf/pdf/1019705/OSRAM/SFH206K.html

Texas Instruments. LM358-N datasheet.

https://www.alldatasheet.com/datasheet-pdf/view/538286/TI/LM358-N.html

Université de Toulon. AOP monotension (cours PDF).

http://bravo.univ-tln.fr/er/Cours%20divers/AOP%20monotension.pdf

OSRAM GmbH. SFH206K Silicon PIN Photodiode – Datasheet (archive).

https://www.chipfind.net/datasheet/siemens/sfh206k.htm

ECAM LaSalle Lyon. (Avril 2024) Fatou LANKOANDE. Operational Amplifier and

Applications (cours PDF) – pas de lien, archives personnelles.

NIMH MonkeyLogic. Behavioral control and data acquisition in MATLAB.

https://monkeylogic.nimh.nih.gov/

Google Scholar. Julien Vezoli – Site officiel Google Scholar

https://scholar.google.com/citations?user=1f9xzcQAAAAJ&hl=de

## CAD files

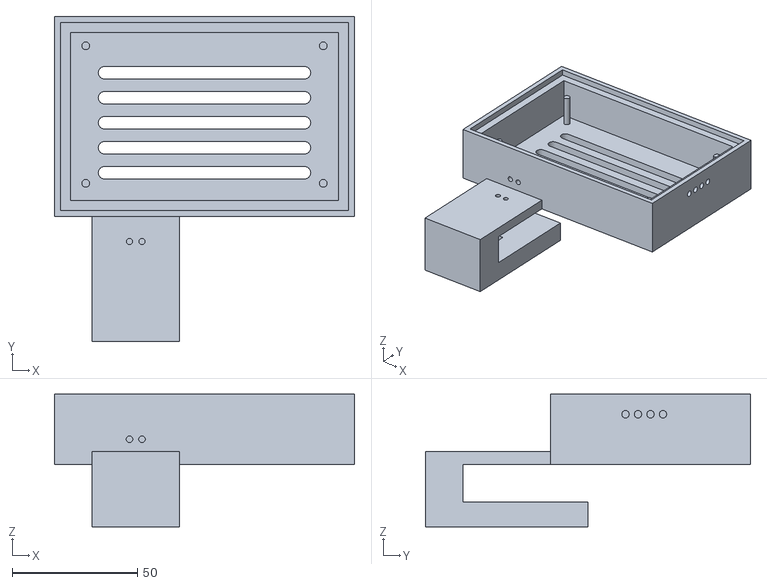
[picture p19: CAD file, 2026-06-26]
bottom_piece.stl
120.0 x 130.0 x 53.0

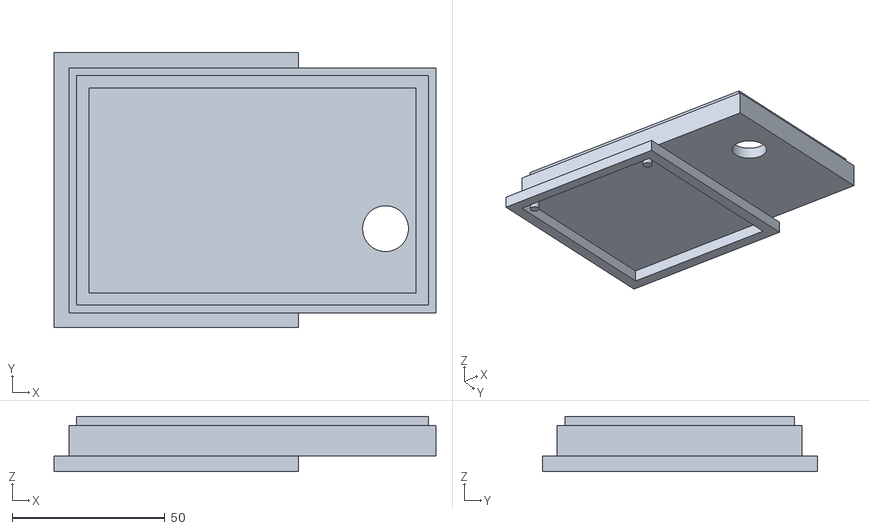
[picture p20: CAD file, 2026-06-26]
top_piece.stl
124.9 x 90.0 x 18.0

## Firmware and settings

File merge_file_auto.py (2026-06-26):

import csv
import os
import tkinter as tk
from tkinter import filedialog, simpledialog

try:
    root = tk.Tk()
    root.withdraw()
    root.attributes('-topmost', True)

    script_dir = os.path.dirname(os.path.abspath(__file__))

    print("Choisis le fichier Arduino...")
    arduino_file = filedialog.askopenfilename(
        parent=root,
        title="Choisis le fichier Arduino (get_*.csv)",
        initialdir=script_dir,
        filetypes=[("CSV files", "*.csv"), ("All files", "*.*")]
    )
    if not arduino_file:
        print("Aucun fichier Arduino sélectionné, arrêt.")
        exit()

    print("Choisis le fichier Keys...")
    keys_file = filedialog.askopenfilename(
        parent=root,
        title="Choisis le fichier Keys (keyPressed_*.csv)",
        initialdir=script_dir,
        filetypes=[("CSV files", "*.csv"), ("All files", "*.*")]
    )
    if not keys_file:
        print("Aucun fichier Keys sélectionné, arrêt.")
        exit()

    print(f"Arduino file name : {os.path.basename(arduino_file)}")
    print(f"Keys file name : {os.path.basename(keys_file)}")

    # essaye de récupérer la date depuis le nom du fichier Arduino (ex: get_2026-06-17_14-22-02.csv)
    arduino_basename = os.path.basename(arduino_file)
    try:
        date_part = arduino_basename.split('_', 1)[1].replace('.csv', '')  # 2026-06-17_14-22-02
    except IndexError:
        date_part = "session"
    default_name = f"merge_{date_part}"

    # demande le nom du fichier de sortie via une popup texte
    root.attributes('-topmost', True)
    root.focus_force()
    merge_name = simpledialog.askstring(
        "Nom du fichier merge",
        "Nom du fichier de sortie (sans .csv) :",
        initialvalue=default_name,
        parent=root
    )
    if not merge_name:
        merge_name = default_name
    if not merge_name.lower().endswith('.csv'):
        merge_name += '.csv'

    arduino_rows = []
    keys_rows = []

    with open(arduino_file, 'r') as f:
        reader = csv.DictReader(f, delimiter=';')
        for row in reader:
            arduino_rows.append({
                'timestamp_pc': int(row['timestamp_pc']),
                'timestamp_arduino': row['timestamp_arduino'],
                'etat': row['etat'],
            })
    print(f"-> {len(arduino_rows)} lignes Arduino lues.")

    with open(keys_file, 'r') as f:
        reader = csv.DictReader(f, delimiter=';')
        for row in reader:
            keys_rows.append({
                'timestamp_pc': int(row['timestamp_pc']),
                'key_pressed': row['key_pressed'],
            })
    print(f"-> {len(keys_rows)} lignes Keys lues.")

    # find SYNC
    sync_reference = None
    for row in keys_rows:
        if row['key_pressed'] == 'SYNC':
            sync_reference = row['timestamp_pc']
            break

    if sync_reference is None:
        print("Error: no SYNC found.")
        exit()
    print(f"-> SYNC trouvé à timestamp_pc = {sync_reference}")

    # offset everything to SYNC
    for row in arduino_rows:
        row['timestamp_pc'] = row['timestamp_pc'] - sync_reference
    for row in keys_rows:
        row['timestamp_pc'] = row['timestamp_pc'] - sync_reference

    # remove arduino rows before SYNC
    arduino_rows = [row for row in arduino_rows if row['timestamp_pc'] >= 0]
    print(f"-> {len(arduino_rows)} lignes Arduino après SYNC.")

    # propagate last known key to each arduino row
    current_key = ''
    key_index = 0

    result = []
    for row in arduino_rows:
        while key_index < len(keys_rows) and keys_rows[key_index]['timestamp_pc'] <= row['timestamp_pc']:
            if keys_rows[key_index]['key_pressed'] != 'SYNC':
                current_key = keys_rows[key_index]['key_pressed']
            key_index += 1
        result.append({
            'timestamp_pc': row['timestamp_pc'],
            'timestamp_arduino': row['timestamp_arduino'],
            'etat': row['etat'],
            'key_pressed': current_key,
        })

    merge_path = os.path.join(script_dir, merge_name)
    with open(merge_path, 'w', newline='') as f:
        writer = csv.DictWriter(f, delimiter=';', fieldnames=['timestamp_pc', 'timestamp_arduino', 'etat', 'key_pressed'])
        writer.writeheader()
        writer.writerows(result)

    print(f"\nMerge file created — {len(result)} rows. ({merge_path})")

except Exception as e:
    import traceback
    print("\n--- ERREUR ---")
    traceback.print_exc()

input("\nAppuie sur Entrée pour fermer...")

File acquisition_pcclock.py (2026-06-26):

import serial
import csv
import time
from datetime import datetime

port = "COM3"
baud = 115200
duree = 7200

name_file = "get_" + datetime.now().strftime("%Y-%m-%d_%H-%M-%S") + ".csv" #add full path in front of get_ to save it in chosen place

arduino = serial.Serial(port, baud, timeout=0.01)
time.sleep(2)

with open(name_file, 'w', newline='') as file:
    crea = csv.writer(file, delimiter=';')
    crea.writerow(["timestamp_arduino", "etat", "timestamp_pc"])

    debut = time.time()

    try:
        while time.time() - debut < duree:
            line = arduino.readline().decode('utf-8', errors='ignore').strip()
            if "," in line:
                parties = line.split(",")
                if len(parties) >= 2:
                    timestamp = parties[0]
                    etat = parties[1]
                    ts_pc = int(time.time() * 1_000_000)
                    crea.writerow([timestamp, etat, ts_pc])
                    print(f"Timestamp: {timestamp}µs, Etat: {etat}")

    except KeyboardInterrupt:
        print("Acquisition stopped by user.")

    except Exception as e:
        print(f"Erreur : {e}")

    finally:
        arduino.close()
        print(f"Acquisition finished. Data saved to {name_file}.")
